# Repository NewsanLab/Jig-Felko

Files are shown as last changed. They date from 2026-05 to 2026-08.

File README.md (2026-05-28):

# Sistema de Testeo de Antenas Felko - Documentación

## Descripción General

Sistema de testeo automatizado para antenas automotrices (modelo ANTENAHILUX) que integra hardware embebido con análisis de señales RF. El sistema consta de dos componentes principales que se comunican vía USB CDC:

- **code.py**: Firmware para placa Archi (CircuitPython) - Control de hardware y adquisición de datos
- **felko.py**: Aplicación PC (Python) - Análisis RF, comunicación con analizador de redes y gestión de datos

## Arquitectura del Sistema

```
┌─────────────────────────────────────────────────────────────┐
│                         INTERFAZ WEB                         │
│                    (Socket.IO Cliente)                       │
└─────────────────────┬───────────────────────────────────────┘
                      │ WebSocket (Puerto 4000)
┌─────────────────────▼───────────────────────────────────────┐
│                        PC (felko.py)                        │
│  ┌────────────────────────────────────────────────────────┐ │
│  │ • Socket.IO Server                                     │ │
│  │ • Control de Analizador de Redes (PyVISA)             │ │
│  │ • Switch RF (mcl_RF_Switch_Controller)                │ │
│  │ • Procesamiento de señales FM/AM                      │ │
│  │ • POST a servidor de trazabilidad                     │ │
│  └────────────────────────────────────────────────────────┘ │
└─────────────────────┬───────────────────────────────────────┘
                      │ USB CDC Serial (115200 baud)
┌─────────────────────▼───────────────────────────────────────┐
│                    ARCHI (code.py)                           │
│  ┌────────────────────────────────────────────────────────┐ │
│  │ • Escáner QR (GM65 - UART 9600)                        │ │
│  │ • Sensor INA260 (I²C) - Voltaje/Corriente             │ │
│  │ • Matriz LED NeoPixel 8x8                              │ │
│  │ • Buzzer para alertas                                  │ │
│  │ • Control de MOSFET y prensa neumática                 │ │
│  │ • Botón de inicio y sensor de barrera                  │ │
│  │ • Botón de emergencia (análogo GP27)                   │ │
│  └────────────────────────────────────────────────────────┘ │
└─────────────────────────────────────────────────────────────┘
                      │
┌─────────────────────▼───────────────────────────────────────┐
│              Analizador de Redes (Keysight)                  │
│         USB0::0x0957::0x1309::MY49304399::0::INSTR           │
└─────────────────────────────────────────────────────────────┘
```

## 1. Firmware Archi - code.py

### Hardware Requerido

#### Comunicación
- **Escáner QR GM65**: UART en GP4 (TX), GP5 (RX), 9600 baud
- **USB CDC**: Comunicación serial con PC a 115200 baud

#### Sensores y Actuadores
- **INA260**: Sensor I²C de corriente/voltaje en GP17 (SCL), GP16 (SDA)
- **Matriz NeoPixel**: 8x8 LEDs RGB (64 píxeles, brillo 10%)
- **Buzzer**: Señal audible en `board.BUZZER`
- **MOSFET**: Control de alimentación en GP14
- **Prensa**: Actuador neumático en GP8
- **LED Inicio**: Indicador de estado en GP28
- **Barrera**: Sensor de seguridad en GP26 (entrada digital)
- **Botón Inicio**: GP18 con debouncer
- **Botón Emergencia**: Entrada analógica en GP27 (threshold > 10000)
- **Botón A**: `board.A` (función legacy)

### Flujo de Operación

#### 1. Inicialización
```
- Configurar hardware (I²C, UART, GPIO)
- Matriz LED en BLANCO (sistema listo)
- Habilitar LED de inicio
- Lanzar tareas asíncronas (asyncio)
```

#### 2. Escaneo QR
```
Usuario presiona botón de inicio
  └─> Verificar barrera (debe estar abierta)
      └─> Si waiting_reset==True: reiniciar (matriz BLANCO)
      └─> Si waiting_reset==False: iniciar escaneo
          ├─> Enviar SOFT_TRIG_ON al GM65
          ├─> Matriz LED → AZUL (escaneando)
          └─> Timeout 5 segundos
              ├─> QR detectado: procesar código
              └─> Timeout: volver a BLANCO
```

#### 3. Validación y Test
```
QR recibido
  └─> Enviar a PC: "#<qr_code>\n"
      └─> PC valida contra base de datos
          ├─> OK: PC envía "FM-START"
          │   └─> Iniciar test FM/AM
          └─> FAIL: PC envía "NG-DB"
              └─> Matriz ROJO + buzzer 1.5s
```

### Estados de la Matriz LED

| Color | Código RGB | Significado |
|---|---|---|
| BLANCO | 0xFFFFFF | Sistema listo para escanear |
| AZUL | 0x0000FF | Escaneando QR |
| AMARILLO | 0xFFFF00 | Test en progreso |
| VERDE | 0x33CC00 | Test OK |
| ROJO | 0xFF0000 | Fallo o emergencia |

### Protocolo de Test FM

```python
1. PC envía: "FM-START"
   └─> Archi responde:
       ├─> Matriz LED → AMARILLO
       ├─> Activar MOSFET (alimentación DUT)
       ├─> Activar prensa (1.25s delay)
       └─> Loop de monitoreo:
           ├─> Leer voltaje INA260 (rango: 7-15.99V)
           ├─> Leer corriente INA260 (límite: <120mA)
           ├─> Si fuera de rango: validacion=0
           └─> Esperar comando PC

2. PC envía resultado:
   ├─> "FM-0" (OK): 
   │   ├─> Si validacion==1: Matriz VERDE, enviar "FM-END-C"
   │   └─> Si validacion==0: Matriz ROJO, enviar "FM-END-E, <current>"
   │
   └─> "FM-2" o "FM-3" (FAIL):
       └─> Matriz ROJO, enviar "FM-END-D", buzzer 1.5s
```

### Protocolo de Test AM

```python
1. PC envía: "AM-START"
   └─> Archi responde:
       ├─> Enviar "AM-RUN"
       ├─> Matriz LED → AMARILLO
       └─> Loop de monitoreo (igual que FM):
           ├─> Validar voltaje: 7-15.99V
           ├─> Validar corriente: <120mA
           └─> Esperar comando PC

2. PC envía resultado:
   ├─> "AM-0" (OK):
   │   ├─> Si validacion==1: Matriz VERDE, enviar "AM-END-C"
   │   └─> Si validacion==0: Matriz ROJO, enviar "AM-END-E, <current>"
   │
   └─> "AM-1" (FAIL):
       └─> Matriz ROJO, enviar "AM-END-D", buzzer 1.5s

3. Finalización:
   ├─> Desactivar prensa (delay 1.3s)
   ├─> Habilitar LED de inicio
   └─> waiting_reset = True (esperar reset del operador)
```

### Tarea de Emergencia (Asíncrona)

```python
Loop infinito (10ms):
  └─> Leer botón emergencia (GP27)
      └─> Si valor > 10000:
          ├─> Matriz LED → ROJO
          ├─> Buzzer 440Hz, 0.3s
          └─> Delay 0.2s
```

### Límites de Seguridad

| Parámetro | Mínimo | Máximo | Acción si Viola |
|---|---|---|---|
| Voltaje DUT | 7.0 V | 15.99 V | validacion=0, enviar corriente en END-E |
| Corriente DUT | - | 120 mA | validacion=0, enviar corriente en END-E |
| Timeout escaneo | - | 5 s | Cancelar escaneo, volver a BLANCO |

---

## 2. Aplicación PC - felko.py

### Dependencias Principales

```python
pyvisa                  # Control de analizador de redes
pyserial                # Comunicación USB CDC con Archi
python-socketio         # WebSocket server para frontend
eventlet                # Servidor WSGI asíncrono
numpy                   # Procesamiento de datos
requests                # POST a servidor de trazabilidad
pythonnet (clr)         # Interfaz .NET para switch RF
```

### Arquitectura de Comunicación

#### 1. Socket.IO Server (Puerto 4000)

```python
Eventos manejados:
├─> connect: Cliente frontend conectado
├─> start-test: Recibe lista de QRs válidos desde frontend
│   └─> Activa validate_code_db = True
│   └─> Almacena json_data_db
└─> Emite:
    └─> test-result: Resultados de test al frontend
```

#### 2. Serial USB CDC (115200 baud)

```python
Conexión con Archi:
├─> VID: 11914 (0x2E8A)
└─> PID: 4163 (0x1043)

Auto-reconexión:
└─> Si desconectado: buscar puerto cada 1s
```

#### 3. PyVISA - Analizador de Redes

```python
Resource: 'USB0::0x0957::0x1309::MY49304399::0::INSTR'
Timeout: 10000 ms

Estados de configuración:
├─> FM: Carga "FM_ganancia_configurada.sta"
└─> AM: Carga "AM_gain20.sta"
```

#### 4. Switch RF (mcl_RF_Switch_Controller)

```python
Librería .NET: mcl_RF_Switch_Controller_NET45.dll
Configuración:
├─> sw.Set_Switch("A", 0)  # Lado FM
└─> sw.Set_Switch("B", 0)
```

### Flujo de Operación Principal

#### 1. Bucle de Conexión

```python
while True:
    # 1. Verificar conexión serial Archi
    if not ser.is_open:
        buscar_puerto(VID=11914, PID=4163)
        conectar_serial(115200 baud)
    
    # 2. Verificar conexión analizador
    if not network_analyzer:
        conectar_visa('USB0::0x0957::0x1309::...')
        query('*IDN?')  # Validar respuesta
    
    # 3. Heartbeat
    else:
        network_analyzer.query('*OPC?')
```

#### 2. Recepción de QR

```python
Archi envía: "#<qr_code>\n"
  └─> PC recibe en buffer
      └─> Si buffer.startswith("#"):
          ├─> Extraer qr_code = buffer[1:]
          ├─> Validar contra json_data_db
          │   ├─> Si código válido: validacion=1
          │   └─> Si código inválido: validacion=0
          │
          └─> Si código == golden_board:
              └─> Ejecutar test con golden sample
```

### Protocolo de Test FM

#### Parámetros de Barrido

```python
POWER_START_DBM = -14.5
POWER_STOP_DBM = -9.7
POWER_STEP_DBM = 0.2

Niveles de potencia:
power_levels = [-14.5, -14.3, -14.1, ..., -9.9, -9.7] dBm
Total: ~25 puntos de medición
```

#### Secuencia de Test FM

```python
1. Enviar a Archi: "FM-START"
   
2. Loop de mediciones (para cada power_level):
   └─> Configurar analizador:
       ├─> Cargar estado "FM_ganancia_configurada.sta"
       ├─> Establecer potencia: f'SOURce1:POWer:LEVel:IMMediate:AMPLitude {power_dbm}'
       ├─> Iniciar barrido: 'INITiate:IMMediate'
       ├─> Esperar OPC
       └─> Guardar datos: 'MMEMory:STORe:FDATa "fm_lectura.csv"'
   
   └─> Leer datos binarios:
       ├─> data = query_binary_values(':MMEMory:TRANsfer? "FM_LECTURA.CSV"')
       └─> Guardar en: "C:\...\fm_comparacion.csv"
   
   └─> Procesar CSV:
       ├─> Leer frecuencias: fm_freq_nuevo (MHz)
       ├─> Leer magnitudes: fm_mag_nuevo (dB)
       └─> Encontrar ganancia en rango 88-99 MHz:
           ├─> gain_real = max(magnitudes[88-99 MHz])
           ├─> gain_ideal = 87.7 + (power_dbm + 14.0) / 4.8 * 16.7
           ├─> gain_dif = abs(gain_real - gain_ideal)
           └─> Si gain_dif < 1.0:
               ├─> validacionAGC = 1
               ├─> Guardar (entrada, salida) para reporte
               └─> Break loop (ganancia encontrada)

3. Enviar resultado a Archi:
   └─> f"FM-{validacionAGC}\n"
       ├─> validacionAGC=1 → "FM-1" (test exitoso)
       └─> validacionAGC=0 → "FM-0" (fallo)

4. Esperar confirmación Archi:
   ├─> "FM-END-C": OK completo
   ├─> "FM-END-D": Fallo RF
   └─> "FM-END-E, <current>": Fallo corriente
```

### Protocolo de Test AM

```python
1. Enviar a Archi: "AM-START"
   
2. Esperar: "AM-RUN" (confirmación de Archi)
   
3. Configurar analizador:
   ├─> Cargar estado "AM_gain20.sta"
   ├─> Delay 2 segundos (estabilización)
   ├─> Guardar datos: 'MMEMory:STORe:FDATa "am_lectura.csv"'
   └─> Transferir: query_binary_values(':MMEMory:TRANsfer? "AM_LECTURA.CSV"')
   
4. Procesar CSV:
   ├─> Leer frecuencias: am_freq_nuevo (kHz)
   ├─> Leer magnitudes: am_mag_nuevo (dB)
   └─> Buscar ganancia en 900-1400 kHz:
       ├─> gain_max = max(magnitudes[900-1400 kHz])
       └─> Si gain_max > 0:
           ├─> validacion = 1 (AM OK)
           └─> Else: validacion = 0

5. Enviar resultado a Archi:
   └─> f"AM-{validacion}\n"

6. Esperar confirmación Archi:
   ├─> "AM-END-C": OK completo
   ├─> "AM-END-D": Fallo RF
   └─> "AM-END-E, <current>": Fallo corriente
```

### Estructura de Datos de Medición

```python
medicion_data = {
    "id_cama": 1,
    "fm": {
        "Frequency_MHz": [88.0, 88.5, ..., 108.0],  # Lista de frecuencias
        "Data1": [65.234, 67.891, ..., 55.123]      # Magnitudes en dB
    },
    "am": {
        "Frequency_MHz": [530.0, 540.0, ..., 1710.0],
        "Data1": [12.456, 15.789, ..., 8.234]
    },
    "agc": {
        "entrada": -12.5,    # dBm de entrada para AGC correcto
        "salida": 87.7       # Ganancia obtenida
    },
    "modos": ["MODOFM-AGC", "MODO AM"],
    "estado": ["OK-FM", "OK-AM"],  # o ["FALLA-FM"], ["FALLA-AM"], ["FALLA-CORRIENTE-FM"]
    "corriente": []  # o ["corriente-fm: 150.5"] si hay falla
}
```

### POST a Servidor de Trazabilidad

```python
URL: '/insertar_automotriz'

Payload:
{
    "codigo": "<qr_code>",
    "testeo": "<medicion_data en JSON string>",
    "estado": 1,
    "modelo": "ANTENAHILUX"
}
```

### Emisión Socket.IO

```python
server_data = {
    "cama": 1,
    "code": "<qr_code>",
    "statusTraza": True,          # Siempre True si llegó a este punto
    "statusJig": True/False,      # True si {"OK-FM", "OK-AM"} ambos presentes
    "message": ["OK-FM", "OK-AM"] # o estados de falla
}

sio.emit("test-result", [server_data])
```

---

## Protocolo de Comunicación Serial

### Mensajes Archi → PC

| Mensaje | Descripción | Acción PC |
|---|---|---|
| `#<qr_code>\n` | Código QR escaneado | Validar en BD, iniciar test |
| `AM-RUN\n` | Archi listo para test AM | Continuar secuencia AM |
| `FM-END-C\n` | FM OK | Guardar estado "OK-FM" |
| `FM-END-D\n` | FM fallo | Guardar estado "FALLA-FM" |
| `FM-END-E, <mA>\n` | FM fallo corriente | Guardar estado "FALLA-CORRIENTE-FM" |
| `AM-END-C\n` | AM OK | Guardar estado "OK-AM", enviar reporte |
| `AM-END-D\n` | AM fallo | Guardar estado "FALLA-AM", enviar reporte |
| `AM-END-E, <mA>\n` | AM fallo corriente | Guardar estado "FALLA-CORRIENTE-AM", enviar reporte |

### Mensajes PC → Archi

| Mensaje | Descripción | Acción Archi |
|---|---|---|
| `FM-START\n` | Iniciar test FM | Activar MOSFET/prensa, monitorear corriente |
| `FM-0\n` | FM resultado: FAIL AGC | Evaluar corriente local, enviar END |
| `FM-1\n` | FM resultado: OK AGC | Evaluar corriente local, enviar END |
| `FM-2\n` | FM resultado: FAIL general | Matriz ROJO, enviar FM-END-D |
| `FM-3\n` | FM resultado: FAIL general | Matriz ROJO, enviar FM-END-D |
| `AM-START\n` | Iniciar test AM | Enviar AM-RUN, monitorear corriente |
| `AM-0\n` | AM resultado: OK | Evaluar corriente local, enviar END |
| `AM-1\n` | AM resultado: FAIL | Matriz ROJO, enviar AM-END-D |
| `NG-DB\n` | QR no válido en BD | Matriz ROJO, buzzer, esperar reset |

---

## Configuración de Archivos

### Archivos de Estado del Analizador

Ubicación: Memoria interna del analizador de redes

```
FM_ganancia_configurada.sta  → Configuración para barrido FM (88-108 MHz)
AM_gain20.sta                → Configuración para barrido AM (530-1710 kHz)
```

### Archivos CSV Temporales (PC)

```
C:\Users\Traza-Lab\AppData\Local\Programs\trazabilidad-newsan\bin\
├─> fm_comparacion.csv   # Datos FM por cada nivel de potencia
└─> am_comparacion.csv   # Datos AM (único barrido)
```

### Estructura CSV del Analizador

```csv
Frequency (MHz/kHz), <trace_name>
88.0, 65.234
88.5, 67.891
...
```
---

## Manejo de Errores

### Archi (code.py)

| Condición | Acción |
|---|---|
| Timeout escaneo QR (5s) | Cancelar escaneo, matriz BLANCO |
| Voltaje fuera de rango | `validacion=0`, enviar corriente en END-E |
| Corriente > 120mA | `validacion=0`, enviar corriente en END-E |
| Botón emergencia activado | Matriz ROJO, buzzer continuo |
| Barrera cerrada | No permitir inicio de escaneo |
| Error decodificación QR | Imprimir error, resetear buffer |

### PC (felko.py)

| Condición | Acción |
|---|---|
| Serial desconectado | Bucle de reconexión cada 1s |
| Analizador desconectado | Bucle de reconexión (PyVISA) |
| Código QR no en BD | Enviar `NG-DB` a Archi |
| Error POST trazabilidad | Imprimir error, continuar operación |
| Error query analizador | Desconectar, intentar reconexión |

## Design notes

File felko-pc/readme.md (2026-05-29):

# Nota sobre el archivo `felko.py`

## ⚠️ Importante

En este repositorio, el archivo se llama **`felko.py`**.
Sin embargo, **en el entorno de producción debe ser renombrado a `yazaki.py`**.

## 📌 Motivo

El sistema en producción depende explícitamente del nombre `yazaki.py` para ejecutar o integrar este módulo.
Por esta razón, el cambio de nombre es obligatorio al momento de subirlo a produccion.

## 🧠 Consideraciones

* En desarrollo y en el repositorio se mantiene el nombre `felko.py` por claridad.
* En producción se utiliza `yazaki.py` por compatibilidad con el sistema existente.
* El contenido del archivo es el mismo; solo cambia el nombre.

## 🚫 No olvidar

* ❌ No ejecutar el sistema en producción con el nombre `felko.py`
* ❌ No subir cambios al repositorio con el nombre `yazaki.py`

---

# Requisitos del entorno

## 🐍 Python

* Python `3.13.12`

## 📚 Librerías requeridas

Instalar las siguientes librerías:

```bash
pip install eventlet
pip install pyvisa
pip install pyvisa-py
pip install pyserial
pip install python-socketio
pip install requests
pip install pythonnet
```

O bien:

```bash
pip install eventlet pyvisa pyvisa-py pyserial python-socketio requests pythonnet
```

---

# Drivers y dependencias adicionales

## 🔌 Driver CH340/CH341

Descargar e instalar:

https://www.wch-ic.com/downloads/ch341ser_exe.html

## 🧩 Visual C++ Redistributable for Visual Studio 2015

Descargar e instalar:

https://www.microsoft.com/es-es/download/details.aspx?id=48145

## ⚡ Controlador / IO Libraries Suite de Keysight

Descargar e instalar:

https://www.keysight.com/us/en/lib/software-detail/computer-software/io-libraries-suite-downloads-2175637.html

---

Ante cualquier cambio en este comportamiento, actualizar este documento.

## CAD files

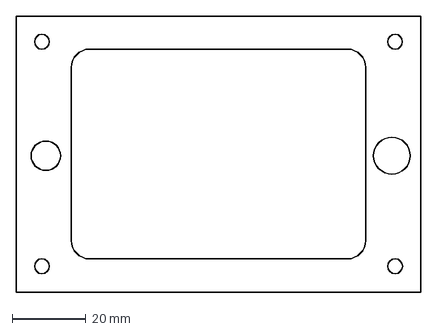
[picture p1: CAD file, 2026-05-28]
design-files/DXF/PreCamaPines.DXF
110.0 x 75.0 mm

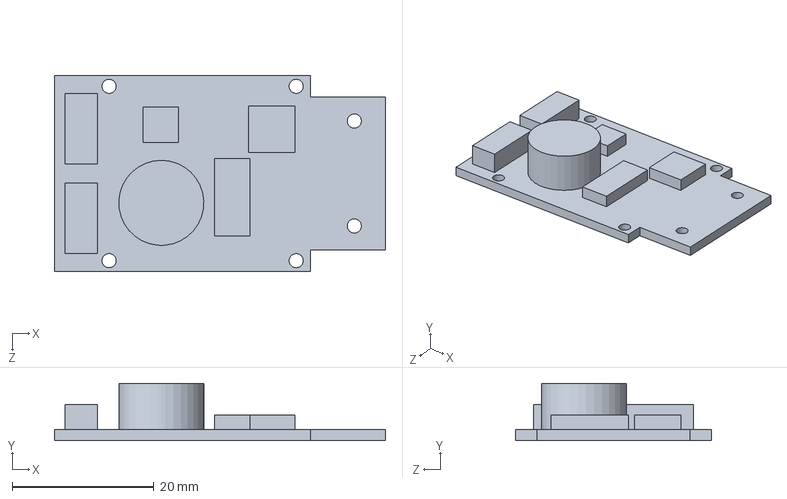
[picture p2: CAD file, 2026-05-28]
design-files/SLDPRT/PlacaLector GM65.SLDPRT
46.7 x 8.10 x 27.7 mm

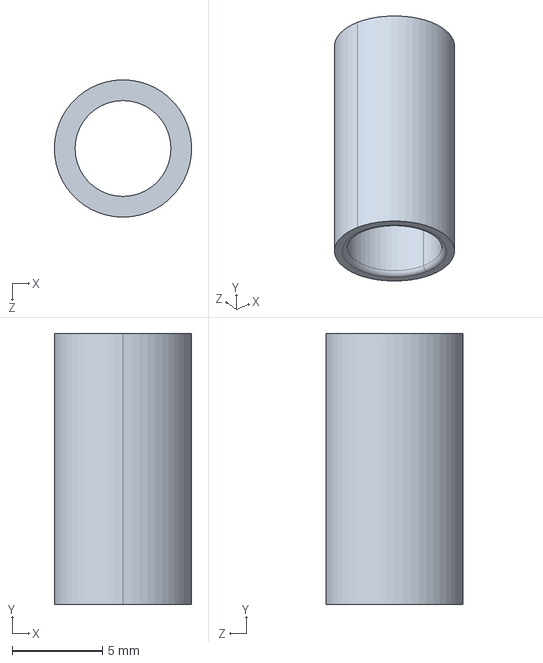
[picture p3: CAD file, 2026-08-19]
design-files/STEP/Guia5mmBuje.STEP
7.60 x 15.0 x 7.60 mm

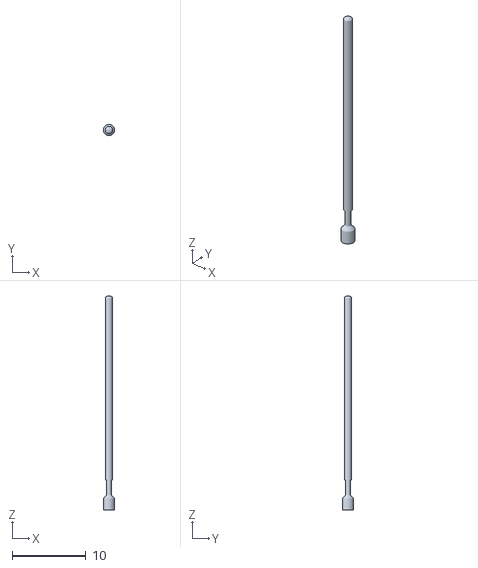
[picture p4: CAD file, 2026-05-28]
design-files/STL/Auxiliares de simulacion en diseño/FelkoV3_2026 - ICT 075-2 ICT 075.STEP-1 ICT 075 A_1.STEP-1.STL
1.52 x 1.52 x 29.0

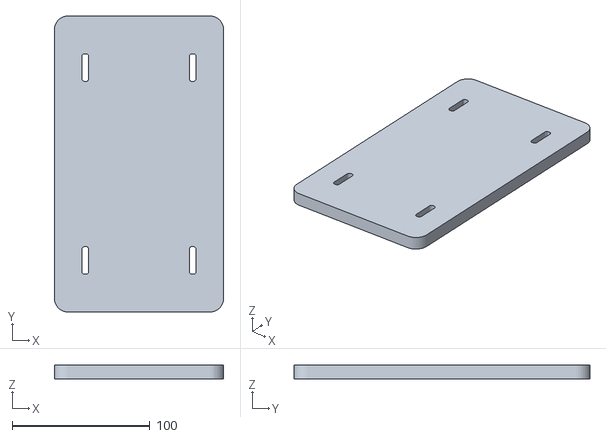
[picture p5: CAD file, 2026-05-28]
design-files/STL/FelkoV3_2026 - part jig 04-1.STL
123.0 x 215.0 x 10.0

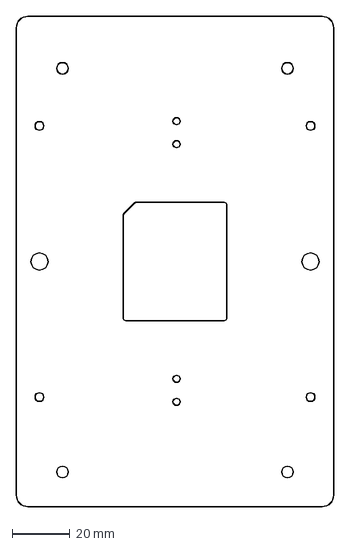
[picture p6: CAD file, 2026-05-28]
design-files/DXF/PlatAluminio 8mm.DXF
110.0 x 170.0 mm

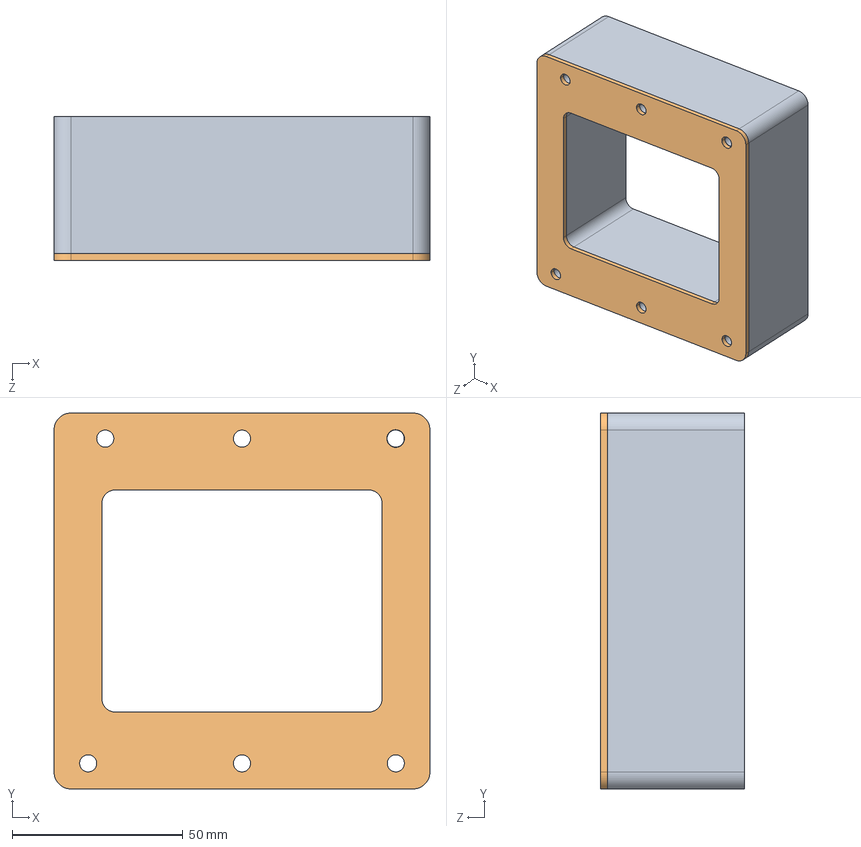
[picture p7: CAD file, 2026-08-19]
design-files/STEP/Pieza4^Felko.STEP
110.0 x 110.0 x 42.0 mm

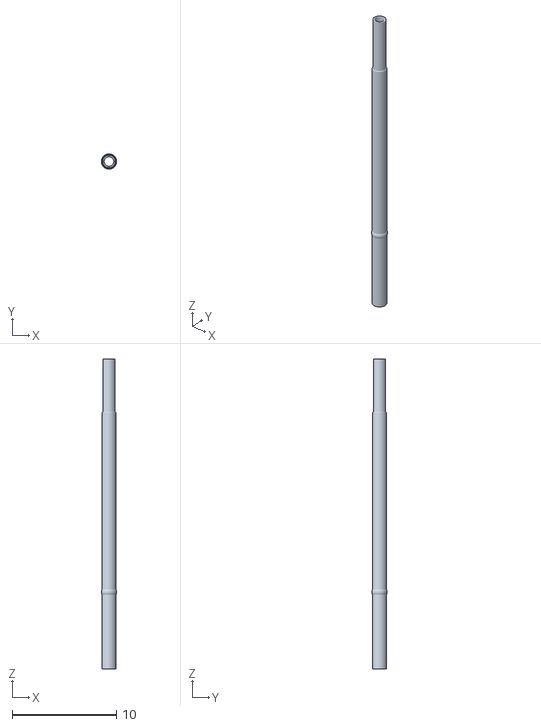
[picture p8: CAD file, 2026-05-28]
design-files/STL/Auxiliares de simulacion en diseño/FelkoV3_2026 - ICT 075-5 ICT 075.STEP-1 R-075-CR_1.STEP-1.STL
1.47 x 1.47 x 29.7

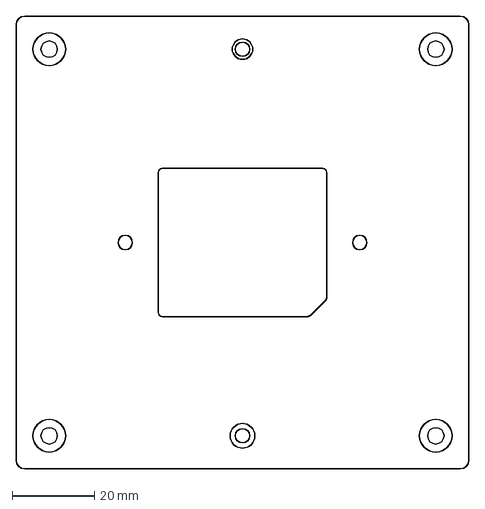
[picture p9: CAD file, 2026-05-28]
design-files/DXF/PlatinaAlumnio20mm 1.DXF
110.0 x 110.0 mm

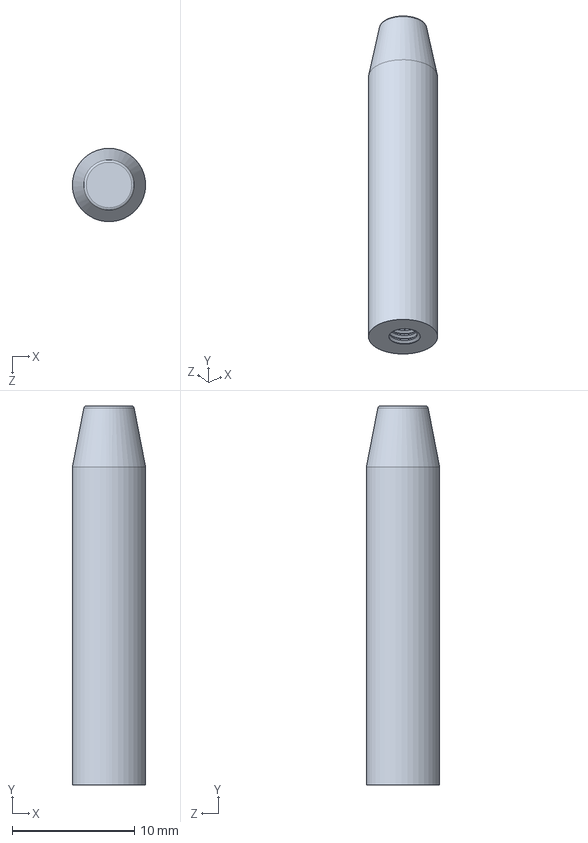
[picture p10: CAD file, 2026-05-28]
design-files/SLDPRT/PernoGuia6mm.SLDPRT
6.00 x 31.0 x 6.00 mm

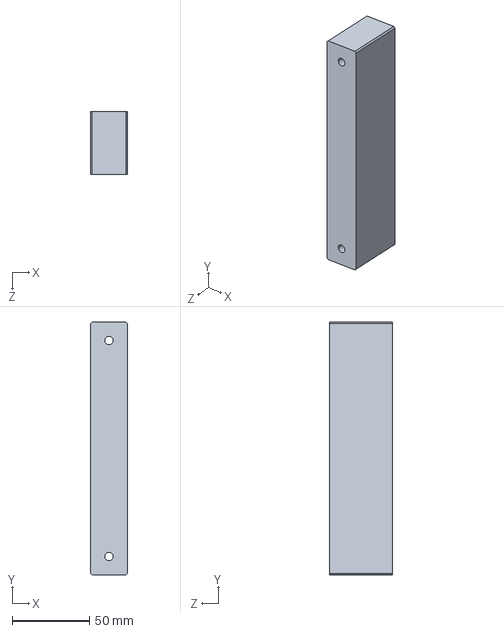
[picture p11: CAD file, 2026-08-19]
design-files/STEP/part jig 03.STEP
24.0 x 164.0 x 41.0 mm

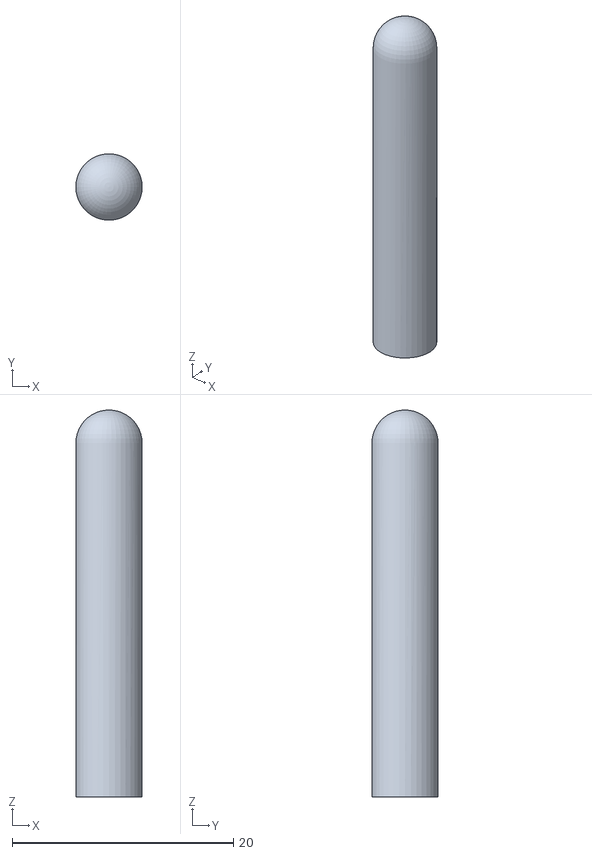
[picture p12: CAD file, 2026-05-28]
design-files/STL/Auxiliares de simulacion en diseño/FelkoV3_2026 - guias placa-4.STL
6.00 x 6.00 x 35.0

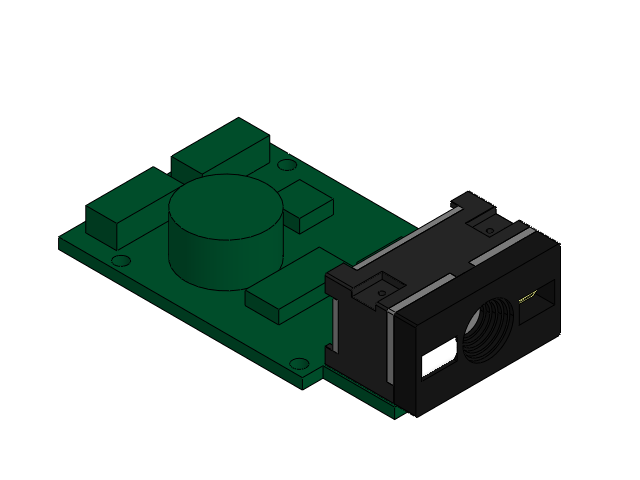
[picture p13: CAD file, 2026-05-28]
design-files/SLDPRT/EnsamLector GM65.SLDASM
Lector GM65
PCB2.STEP
C0402.STEP
R0402.STEP
SOT_23.STEP
FFC2B28-12-G001.STEP
Cylinder.STEP
SLED-000007404_000.STEP
TQFP_64_7x7mm_P04mm.STEP
FRONT_BLK.STEP
PCB1.STEP
BACK_BLK.STEP

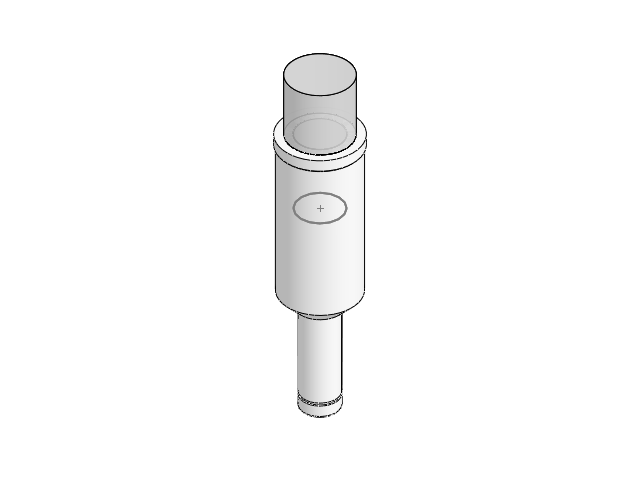
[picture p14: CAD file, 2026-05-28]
design-files/SLDPRT/EnsamPinApPcb.SLDASM
CilindoPinApoyoPcb
IntPinApoyoPcb
GomaPinApoyoPcb

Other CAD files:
design-files/SLDPRT/Retractil Cama Pcba.SLDASM
design-files/SLDPRT/ICT 075.SLDASM
design-files/SLDPRT/EnsamblajeLector GM65.SLDASM
design-files/STL/FelkoV3_2026 - Pieza4^Felko-1.STL
design-files/DXF/Felko pines.DXF
design-files/SLDPRT/Anclaje Cadena.SLDPRT
design-files/SLDPRT/Anclaje finCadena.SLDPRT
design-files/SLDPRT/BaseAlum_8mm.SLDPRT
design-files/SLDPRT/Bastidor PCBSW.SLDPRT
design-files/SLDPRT/EslabonCadena.SLDPRT
design-files/SLDPRT/Felko Bastidor2.SLDPRT
design-files/SLDPRT/Guia5mmBuje.SLDPRT
design-files/SLDPRT/Guia6mmBuje.SLDPRT
design-files/SLDPRT/PernoGuia5mm.SLDPRT
design-files/SLDPRT/Pieza3^Felko.SLDPRT
design-files/SLDPRT/Pieza4^Felko.SLDPRT
design-files/SLDPRT/PlacaFelko.SLDPRT
design-files/SLDPRT/PlatAlumnio 1.SLDPRT
design-files/SLDPRT/PlatinaAluminio 2.SLDPRT
design-files/SLDPRT/PressPlaca+lectorQR.SLDPRT
design-files/SLDPRT/Tapa jig.SLDPRT
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

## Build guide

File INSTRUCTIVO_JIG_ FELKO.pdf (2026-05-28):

Laboratorio de Diseño y Desarrollo | 2026-04-06
MANUAL DE USO JIG ANTENA | Pág. 1 de 5

## MANUAL DE USO JIG ANTENA

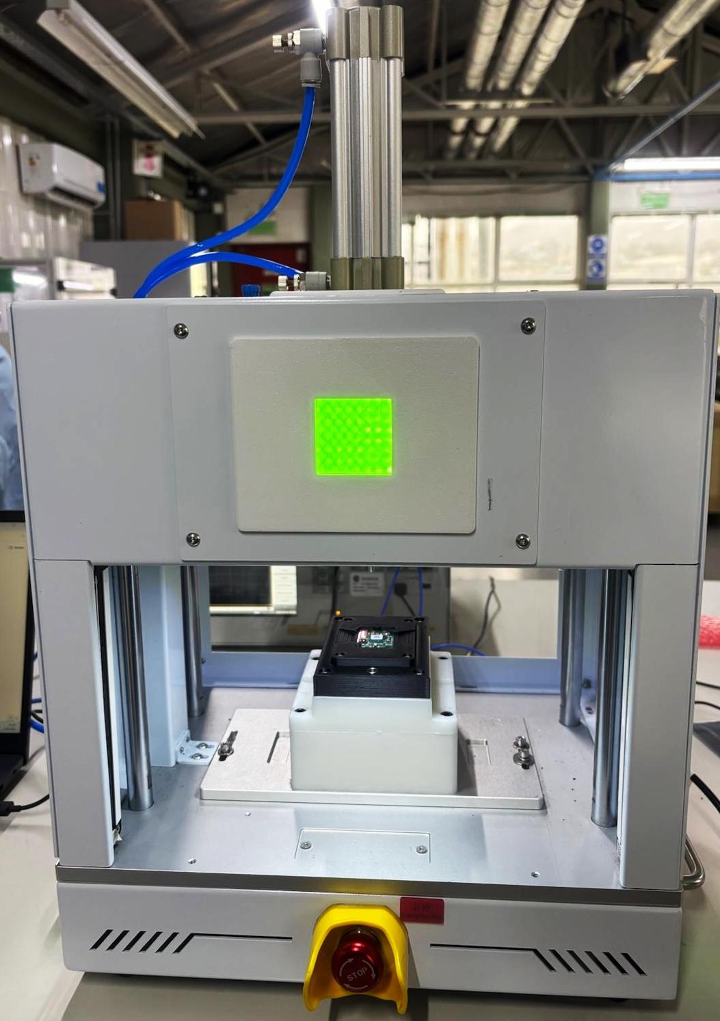
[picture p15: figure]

MANUAL DE USO JIG ANTENA | Pág. 2 de 5

INDICE

MANUAL DE USO JIG ANTENA | Pág. 3 de 5

## 1. DESCRIPCIÓN DE LAS PARTES

El JIG cuenta de las siguientes partes e instrumentos:

- 1 Network Analyzer E5061B Agilent Technologies
- 1 USB RF Switch matrix - USB-4SPDT-A18
- 1 RF Probe
- 1 Microcontrolador Archi
- 1 PC – Notebook Lenovo V15 G4
- 1 Gabinete con Prensa y cama de pines
- 1 Escaner
- 2 Fuente de alimentación 12V
- 1 Fuente de alimentación 24V

## 2. INSTALACIÓN Y ENCENDIDO

Realice la conexión de todas las partes como se muestra en la imagen y en la secuencia que se describe a continuación.

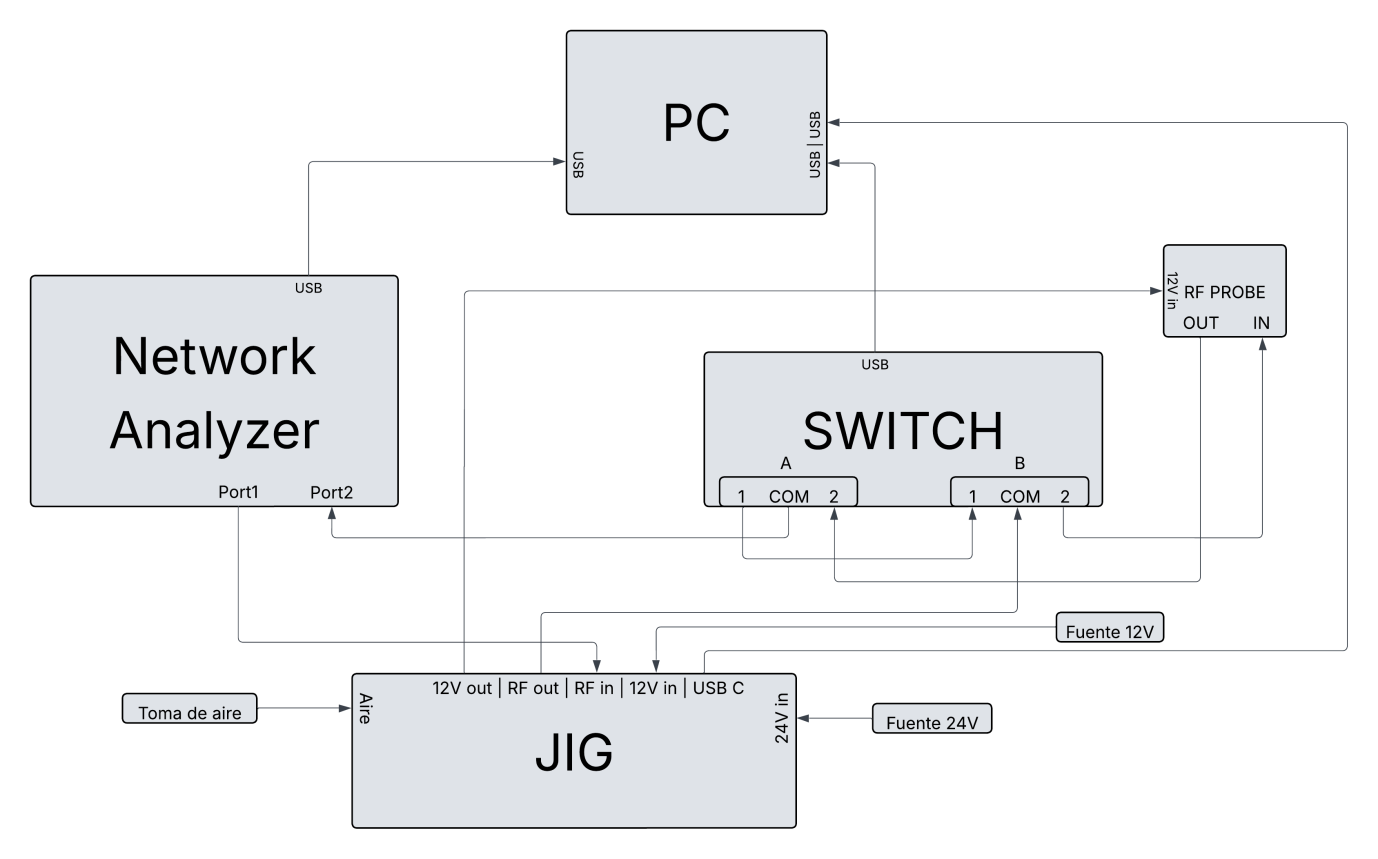
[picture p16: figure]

Ilustración 1: Diagrama de conexión

MANUAL DE USO JIG ANTENA | Pág. 4 de 5

Paso 1: Conexiones de Control (USB)

Es fundamental establecer primero la comunicación con la PC para que el software de gestión reconozca los periféricos.

- PC a Network Analyzer: Conectar un cable USB desde la PC al puerto USB del Analizador de Redes.
- PC a Switch: Conectar un cable USB desde la PC al puerto USB del Switch.
- PC a JIG: Conectar un cable USB desde la PC al puerto USB C del JIG.

Paso 2: Alimentación Eléctrica y Neumática

El sistema utiliza dos fuentes externas de 24V y 12V para alimentar los componentes activos, y aire comprimido para la ejecución del sistema neumático.

- Fuente 12V: Conectar la salida de la Fuente 12V a la entrada 12V in del JIG (parte posterior).
- Fuente 24 V: Conectar la salida de la Fuente 24V a la entrada 24V in del JIG (parte lateral).
- JIG a RF Probe: Conectar el puerto 12V out del JIG a la entrada 12V in del RF Probe.
- AIRE: Conecte la toma de aire al JIG.

Paso 3: Interconexión de RF (Señal)

Orden de conexión para cerrar el lazo de medición entre el analizador, el switch y los dispositivos de prueba.

Bloque A:

- (1) a (1) de bloque B.
- (2) a (Out) de RF Probe.
- (COM) a (Port2) de Analizador

Bloque B:

- (1) a (1) de bloque A.
- (2) a (IN) de RF Probe.
- (COM) a (RF out) de JIG.

JIG:

- (RF in) a (Port1) de Analizador
- (RF out) a (COM) de bloque B

MANUAL DE USO JIG ANTENA | Pág. 5 de 5

Paso 4: Encendido

Conectar cada fuente de alimentación a 220V y encender los equipos, posteriormente ejecutar el programa de testeo.

## 3. PROCEDIMIENTO DE USO

- Colocar la placa a testear en la cama del jig.
- Presionar al mismo tiempo ambos botones laterales.
- El jig activara el escaneo de QR para su validación con DB.
- La prensa se activa en un desplazamiento vertical descendente.
- Se ejecutan las mediciones de:
- FM
- AGC
- AM
- Corriente.
- Finalizado el testeo la prensa realiza un desplazamiento vertical ascendente y los datos se recopilan en DB.

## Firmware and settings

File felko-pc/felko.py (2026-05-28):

import eventlet
from eventlet import wsgi
eventlet.monkey_patch()
import os   
os.environ["EVENTLET_NO_GREENDNS"] = "yes"
from datetime import datetime
from simplification.cutil import simplify_coords #añadido para RDP

import numpy as np
import pyvisa
import time
import csv
import serial
import serial.tools.list_ports
import requests
import sys
import threading
import json 
import socketio
import clr
clr.AddReference(r"C:\Users\Traza-Lab\AppData\Local\Programs\trazabilidad-newsan\bin\mcl_RF_Switch_Controller_NET45.dll")
from mcl_RF_Switch_Controller_NET45 import USB_RF_SwitchBox

base_dir = os.path.dirname(os.path.abspath(__file__))
route_folder = os.path.join(base_dir, "datos")

os.makedirs(route_folder, exist_ok=True)

URL = 'http://arushap02:5000/insertar_automotriz'
API_KEY = "uDnNvsMOGW0MsE6OQrsyKF04Sdey0TQKT1albqCEEms"
json_data_db=[]

sio = socketio.Server(cors_allowed_origins="*")
app = socketio.WSGIApp(sio)

@sio.event
def connect(sid, environ):
    print("cliente conectado")


@sio.on("start-test") 
def start_test(sid, data): 
    """
    Manejador del evento 'start-test'.
    Recibe la lista de códigos QR escaneados desde el frontend y activa la bandera
    de validación para comenzar el ciclo de prueba.
    
    Args:
        sid: ID de la sesión del socket.
        data: JSON string con la lista de objetos de los QRs.
    """
    global validate_code_db, json_data_db
    validate_code_db = True
    print(json_data_db)
    json_data_db = json.loads(data)
    print(json_data_db)
    
def socket_func():
    """
    Función que ejecuta el servidor WSGI con Socket.IO en un hilo separado.
    Escucha en el puerto 4000.
    """
    wsgi.server(eventlet.listen(('', 4000)), app, log=sys.stdout)
    
socket_thread = threading.Thread(target=socket_func, daemon=True)
socket_thread.start()

		
def simplificar_curva(freq_list, data_list):
    coords = list(zip(freq_list, [float(v) for v in data_list]))
    umbral = 0.19  # MHz
    coords_critico = [(f, d) for f, d in coords if f < umbral]
    coords_estable = [(f, d) for f, d in coords if f >= umbral]
    critico_simpl = simplify_coords(coords_critico, epsilon=0.002) if coords_critico else []
    estable_simpl = simplify_coords(coords_estable, epsilon=0.015) if coords_estable else []
    curva_final = sorted(critico_simpl + estable_simpl, key=lambda p: p[0])
    return {
        "Frequency_MHz": [round(f, 6) for f, _ in curva_final],
        "Data1":         [round(d, 6) for _, d in curva_final]
    }

def post_data_testing(data):
    global URL, API_KEY
    try:
        response = requests.post(
          URL,
          json=data,
          headers={
            'arushap02-api-key': API_KEY,             
            'Content-Type': 'application/json' 
          },
          timeout=5 #agregado timeout para evitar bloqueos prolongados en caso de problemas de red
        )
        print(f"POST enviado: {response.status_code}")
    except requests.exceptions.RequestException as e:
        print(f"Error al enviar POST: {e}")

def find_serial_port(vendor_id, product_id):
    ports = serial.tools.list_ports.comports()
    for port in ports:
        if (port.vid == vendor_id) and (port.pid == product_id):
            return port.device
    return None

def connect_serial(port, baudrate=115200, timeout=1):
    try:
        ser = serial.Serial(port, baudrate, timeout=timeout)
        print(f"CONECTADO: {port}")
        return ser
    except serial.SerialException as e:
        print(f"Error al conectar con {port}: {e}")
        return None 

def main():
    global qr_code, validate_code_db, json_data_db

    # variables en comun AM y FM
    VENDOR_ID = 11914
    PRODUCT_ID = 4163
    sw = USB_RF_SwitchBox()
    sw.Connect()
    network_analyzer = None
    rm = pyvisa.ResourceManager()
    qr_code = ""
    golden_board = 'VA004901250413000000358'
    ser = None
    buffer = ''

    # FM
    POWER_START_DBM = -14.5
    POWER_STOP_DBM = -9.7
    POWER_STEP_DBM = 0.2
    power_levels_dbm = np.arange(POWER_START_DBM, POWER_STOP_DBM + POWER_STEP_DBM, POWER_STEP_DBM)
    ser = None
    gain_str = ''
    gain_real = ''
    gain_float = 0
    gain_ideal = 0
    gain_dif = 0
    validacionAGC = 0

    # para usar switch lado FM
    sw.Set_Switch("A",0)
    sw.Set_Switch("B",0)
    end_test_fm = False
    end_test_am = False
    validate_code_db = False
    status = [] # para agregar los estados de test de fm, am
    current_fail = [] # para agregar falla de corriente FM o AM

    while(True):
        # Conexion serial con Archi
        if ser is None or not ser.is_open:
            port = find_serial_port(VENDOR_ID, PRODUCT_ID)
            if port:
                ser = connect_serial(port, 115200, timeout=0.1)
            else:
                print("DESCONECTADO: Buscando puerto USB...")
            time.sleep(1)

        # Conexion con el analizador de redes
        if network_analyzer is None:
            try:
                network_analyzer = rm.open_resource('USB0::0x0957::0x1309::MY49304399::0::INSTR')
                network_analyzer.timeout = 10000
                idn = network_analyzer.query("*IDN?")
                print(f"CONECTADO: Equipo responde [{idn.strip()}]")

            except Exception as e:
                if "VI_ERROR_RSRC_NFOUND" in str(e):
                    print("DESCONECTADO: Equipo no encontrado")
                else:
                    print(f"DESCONECTADO: PyVISA error -> {e}")
                network_analyzer = None

        else:
            try:
                network_analyzer.query("*OPC?")  # solo para verificar que sigue conectado
            except Exception as e:
                print(f"DESCONECTADO: PyVISA error -> {e}")
                network_analyzer = None
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

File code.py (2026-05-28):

import board
import neopixel
from adafruit_pixel_framebuf import PixelFramebuffer
import usb_cdc
import time
from digitalio import DigitalInOut, Direction, Pull
import simpleio
import busio
from adafruit_debouncer import Debouncer
from adafruit_ina260 import INA260
import asyncio
import digitalio
import analogio

pixeles = neopixel.NeoPixel(board.NEOPIXEL, 64, brightness=0.1, auto_write=False)
matriz = PixelFramebuffer(pixeles, 8, 8, alternating=False)

buzzer = board.BUZZER

i2c_ina260 = busio.I2C(board.GP17, board.GP16)  # SCL, SDA
ina260 = INA260(i2c_ina260) # default address of INA260 0x40

# Comandos GM65
SOFT_TRIG_ON = b"\x7E\x00\x08\x01\x00\x02\x01\xAB\xCD"

# Comunicacion UART con scanner GM65
gm65_scnr = busio.UART(board.GP4, board.GP5, baudrate = 9600, timeout=0.01)

MAX_TIME_SCAN = 5 # tiempo maximo de escaneo en segundos seteado con hoja de cfg del escaner

waiting_reset = False

# Colors
FAIL_COLOR = 0xff0000
OK_COLOR = 0x33cc00
READY_COLOR = 0x0000ff
CLEAR_COLOR = 0x000000
WHITE_COLOR = 0xffffff
TEST_COLOR = 0xffff00

def crear_boton(boton):
  boton_value = DigitalInOut(boton)
  boton_value.direction = Direction.INPUT
  boton_value.pull = Pull.UP
  return boton_value

def pintar_matriz(color):
    matriz.fill(color)
    matriz.display()

async def task_emergency():
    btn_emergency = analogio.AnalogIn(board.GP27)
    while True:
        if (btn_emergency.value > 10000):
            pintar_matriz(FAIL_COLOR)
            simpleio.tone(buzzer, 440, duration = 0.3)
            await asyncio.sleep(0.2)
        await asyncio.sleep(0.01)  

async def test_felko(qr_code):
    global btnA, command, validacion, status, isFinishTestFM, serial, press, start_led, ina260, waiting_reset, mosfet                                                    
    # al iniciar el test, se apaga el led de inicio para indicar que el test esta en proceso, y se vuelve a prender al finalizar el test
    start_led.value = False
    serial.write(f"#{qr_code}\n".encode('utf-8'))
    await asyncio.sleep(0.2)
    validacion = 1 # variable que se setea en 0 si hay un fallo en la medicion de corriente o tension, y se mantiene en 1 si las mediciones son correctas 
    end_test = False 
    while not end_test:
        if serial.in_waiting > 0: 
            command = serial.readline().decode('utf-8').strip()
            # print("command:", command) 
            if command == "FM-START":
                pintar_matriz(TEST_COLOR) 
                mosfet.value = True
                press.value = True
                await asyncio.sleep(1.25)
                while command not in ("FM-0", "FM-2", "FM-3"):
                    pintar_matriz(TEST_COLOR)
                    voltage = ina260.voltage  # voltage on V- (load side)
                    current = ina260.current  # current in mA
                    print(f"voltage: {voltage} - corriente: {current}")
                    if ((voltage < 7)|(voltage > 15.99)):
                        validacion = 0
                    if (current > 120):
                        validacion = 0
                    if serial.in_waiting > 0:
                        command = serial.readline().decode('utf-8').strip()
                    await asyncio.sleep(0.01)

                if command in ("FM-2", "FM-3"):#FM fail
                    pintar_matriz(FAIL_COLOR)
                    serial.write("FM-END-D\n".encode('utf-8'))
                    simpleio.tone(buzzer, 440, duration = 1.5)
                if command == "FM-0":#OK
                    if validacion == 1:
                        pintar_matriz(OK_COLOR)
                        serial.write("FM-END-C\n".encode('utf-8'))
                    else:#current fail
                        pintar_matriz(FAIL_COLOR)
                        serial.write(f"FM-END-E, {current}\n".encode('utf-8'))
                        simpleio.tone(buzzer, 440, duration = 1.5)

            if command == "AM-START":
                serial.write("AM-RUN\n".encode('utf-8'))
                pintar_matriz(TEST_COLOR)
                while command not in ("AM-0", "AM-1"):
                    voltage = ina260.voltage  # voltage on V- (load side)
                    current = ina260.current  # current in mA
                    if ((voltage < 7)|(voltage > 15.99)):
                        validacion = 0
                    if (current > 120):
                        validacion = 0
                    if serial.in_waiting > 0:
                        command = serial.readline().decode('utf-8').strip()
                    await asyncio.sleep(0.01)

                if command == "AM-1":#AM fail
                    pintar_matriz(FAIL_COLOR)
                    serial.write("AM-END-D\n".encode('utf-8'))
                    simpleio.tone(buzzer, 440, duration = 1.5) 
                    end_test = True
                    press.value = False
                    await asyncio.sleep(1.3)
                    start_led.value = True
                    waiting_reset = True
                if command == "AM-0":#OK
                    if validacion == 1:
                        pintar_matriz(OK_COLOR)
                        serial.write("AM-END-C\n".encode('utf-8'))
                    else:#current fail
                        pintar_matriz(FAIL_COLOR)
                        serial.write(f"AM-END-E, {current}\n".encode('utf-8'))
                        simpleio.tone(buzzer, 440, duration = 1.5)
                    end_test = True
                    press.value = False
                    await asyncio.sleep(1.3)
                    start_led.value = True 
                    waiting_reset = True
            if command == "NG-DB":
                pintar_matriz(FAIL_COLOR)
                simpleio.tone(buzzer, 440, duration = 1.5)
                end_test = True
                press.value = False
                await asyncio.sleep(1.3)
                start_led.value = True
                waiting_reset = True
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

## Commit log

2026-05-28 project felko
    [Anclaje Cadena.SLDPRT, Anclaje Cadena.STL, Anclaje finCadena.SLDPRT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]
2026-05-29 Update README with environment and library requirements
    Added environment requirements and installation instructions for Python libraries and additional drivers.
